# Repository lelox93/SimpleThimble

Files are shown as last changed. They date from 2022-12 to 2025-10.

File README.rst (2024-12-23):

Example: Basic Sphinx project for Read the Docs
===============================================



.. This README.rst should work on Github and is also included in the Sphinx documentation project in docs/ - therefore, README.rst uses absolute links for most things so it renders properly on GitHub

This example shows a basic Sphinx project with Read the Docs. You're encouraged to view it to get inspiration and copy & paste from the files in the source code. If you are using Read the Docs for the first time, have a look at the official `Read the Docs Tutorial <https://docs.readthedocs.io/en/stable/tutorial/index.html>`__.

📚 `docs/ <https://github.com/readthedocs-examples/example-sphinx-basic/blob/main/docs/>`_
    A basic Sphinx project lives in ``docs/``. All the ``*.rst`` make up sections in the documentation.
⚙️ `.readthedocs.yaml <https://github.com/readthedocs-examples/example-sphinx-basic/blob/main/.readthedocs.yaml>`_
    Read the Docs Build configuration is stored in ``.readthedocs.yaml``.
⚙️ `docs/conf.py <https://github.com/readthedocs-examples/example-sphinx-basic/blob/main/docs/conf.py>`_
    Both the configuration and the folder layout follow Sphinx default conventions. You can change the `Sphinx configuration values <https://www.sphinx-doc.org/en/master/usage/configuration.html>`_ in this file
📍 `docs/requirements.txt <https://github.com/readthedocs-examples/example-sphinx-basic/blob/main/docs/requirements.txt>`_ and `docs/requirements.in <https://github.com/readthedocs-examples/example-sphinx-basic/blob/main/docs/requirements.in>`_
    Python dependencies are `pinned <https://docs.readthedocs.io/en/latest/guides/reproducible-builds.html>`_ (uses `pip-tools <https://pip-tools.readthedocs.io/en/latest/>`_). Make sure to add your Python dependencies to ``requirements.txt`` or if you choose `pip-tools <https://pip-tools.readthedocs.io/en/latest/>`_, edit ``docs/requirements.in`` and remember to run ``pip-compile docs/requirements.in``.
💡 `docs/api.rst <https://github.com/readthedocs-examples/example-sphinx-basic/blob/main/docs/api.rst>`_
    By adding our example Python module ``lumache`` in the reStructuredText directive ``:autosummary:``, Sphinx will automatically scan this module and generate API docs.
💡 `docs/usage.rst <https://github.com/readthedocs-examples/example-sphinx-basic/blob/main/docs/usage.rst>`_
    Sphinx can automatically extract API documentation directly from Python modules, using for instance the ``:autofunction:`` directive.
💡 `lumache.py <https://github.com/readthedocs-examples/example-sphinx-basic/blob/main/lumache.py>`_
    API docs are generated for this example Python module - they use *docstrings* directly in the documentation, notice how this shows up in the rendered documentation.
🔢 Git tags versioning
    We use a basic versioning mechanism by adding a git tag for every release of the example project. All releases and their version numbers are visible on `example-sphinx-basic.readthedocs.io <https://example-sphinx-basic.readthedocs.io/en/latest/>`__.
📜 `README.rst <https://github.com/readthedocs-examples/example-sphinx-basic/blob/main/README.rst>`_
    Contents of this ``README.rst`` are visible on Github and included on `the documentation index page <https://example-sphinx-basic.readthedocs.io/en/latest/>`_ (Don't Repeat Yourself).
⁉️ Questions / comments
    If you have questions related to this example, feel free to can ask them as a Github issue `here <https://github.com/readthedocs-examples/example-sphinx-basic/issues>`_.

Example Project usage
---------------------

This project has a standard Sphinx layout which is built by Read the Docs almost the same way that you would build it locally (on your own laptop!).

You can build and view this documentation project locally - we recommend that you activate `a local Python virtual environment first <https://packaging.python.org/en/latest/guides/installing-using-pip-and-virtual-environments/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>`_:

.. code-block:: console

    # Install required Python dependencies (Sphinx etc.)
    pip install -r docs/requirements.txt

    # Enter the Sphinx project
    cd docs/
    
    # Run the raw sphinx-build command
    sphinx-build -M html . _build/

You can also build the documentation locally with ``make``:

.. code-block:: console

    # Enter the Sphinx project
    cd docs/
    
    # Build with make
    make html
    
    # Open with your preferred browser, pointing it to the documentation index page
    firefox _build/html/index.html

Using the example in your own project
-------------------------------------

If you are new to Read the Docs, you may want to refer to the `Read the Docs User documentation <https://docs.readthedocs.io/>`_.

If you are copying this code in order to get started with your documentation, you need to:

#. place your ``docs/`` folder alongside your Python project. If you are starting a new project, you can adapt the `pyproject.toml` example configuration.
#. use your existing project repository or create a new repository on Github, GitLab, Bitbucket or another host supported by Read the Docs
#. copy ``.readthedocs.yaml`` and the ``docs/`` folder into your project.
#. customize all the files, replacing example contents.
#. add your own Python project, replacing the ``pyproject.toml`` configuration and ``lumache.py`` module.
#. rebuild the documenation locally to see that it works.
#. *finally*, register your project on Read the Docs, see `Importing Your Documentation <https://docs.readthedocs.io/en/stable/intro/import-guide.html>`_.

Read the Docs tutorial
----------------------

To get started with Read the Docs, you may also refer to the `Read the Docs tutorial <https://docs.readthedocs.io/en/stable/tutorial/>`__.
It provides a full walk-through of building an example project similar to the one in this repository.

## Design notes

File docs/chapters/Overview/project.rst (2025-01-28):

AugmentedWearEdu Project
+++++++++++++++++++++++++++++++++++++++++

The main objective of project is to introduce a novel framework for e-Learning consisting of including haptic experiences to enable digital access to laboratories in higher education. This will be achieved by combining both virtual reality (VR) and augmented reality (AR) tools with a novel generation of wearable haptic devices. This combination of low-cost commercial off-the-shelf (COTS) technology (using open-source software and simple physical devices) will make learning in a laboratory and hapto-audiovisual environment possible.

pref
|

One of the biggest drawbacks of the majority of E-learning existing solutions, is that limited support is provided to hands-on laboratory work and practical experiences. Hands-on experiences are essential to significantly advance learning, especially in science, technology, engineering, and mathematics (STEM) departments. The project AugmentedWearEdu will make it possible to engage students in a fully-immersive 3D virtual/augmented educational environment, contributing to performing lab work in a fully-immersive, open, and, most importantly, distance laboratory learning. 

Within this project, the SimpleThimble device will be used to provide haptic feedback to the user, allowing them to feel the virtual environment in a realistic way. The device will be used in combination with VR tools to create a fully immersive learning experience.

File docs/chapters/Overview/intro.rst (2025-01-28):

Welcome to Simple Thimble!
+++++++++++++++++++++++++++++++++++++++++

**Simple Thimble** is an *open-source* and *low-cost* project to build your own VR-enabled force feedback device. It is designed to be easy to 
assemble and use, and can be used with ``Unity`` virtual environment development platform. Moreover the :ref:`3D models<3dPrintingIntro>` for this device can be downloaded from this guide and 3D printed at home!

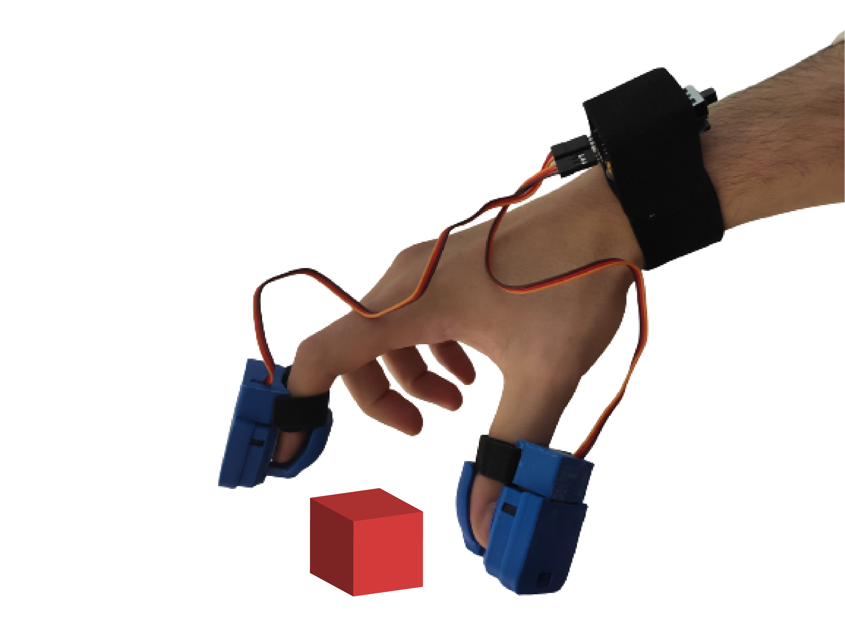
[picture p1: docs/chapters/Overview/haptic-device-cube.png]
Haptic Device

|

Features
-------------------------------------------------------

* **Open-source**: All the hardware and software components are open-source, so you can customize the device to your needs. 
* **Low-cost**: Simple Thimble is designed to be affordable, so anyone can build 
  their own force feedback device. 
* **Easy to assemble**: The device is designed to be easy to assemble, so you 
  don't need any special tools or skills. 
* **VR Compatible**: Simple Thimble is compatible with Unity virtual 
  environment development platform, so you can use it while developing virtual world applications.
* **Force feedback**: Simple Thimble provides realistic force feedback, so you can feel the environment in virtual reality.

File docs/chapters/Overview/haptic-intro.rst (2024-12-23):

Haptic Devices: an overview
+++++++++++++++++++++++++++++++

Haptic devices are tactile feedback devices that allow users to interact with virtual environments. They provide a sense of touch and force feedback to the user, allowing them to feel the effects of their actions in a virtual environment. Haptic devices are used in a variety of applications, including gaming, medical training, and virtual reality.

What is an haptic thimble?
===========================

A haptic thimble is a device used to provide tactile feedback to a user. It is typically worn on the finger and provides a physical sensation when 
interacting with a virtual environment. The thimble can be used to simulate the feeling of touching objects in a virtual world, allowing users to experience a more realistic and immersive experience. 

Grasping Cubes

We can find two simple implementations of an haptic thimble, by providing the fingertip with a vibration of by squeezing it.

Haptic thimble anatomy
----------------------

The haptic thimble is composed of several components, including a motor, sensors, and some mechanical components. The motor is used to generate vibrations, which are then transmitted to the user by using sensors' data. The sensors detect the user's movements and provide feedback to the motor, allowing it to adjust the intensity of the force accordingly.

Applications for an haptic thimble
----------------------------------

The haptic thimble is used in a variety of applications, including virtual reality, gaming, and medical training. It can be used to simulate the feeling of touching objects in a virtual environment, allowing users to experience a more realistic and immersive experience. 

Hand Grasping Cube

Additionally, it can be used to provide tactile feedback during medical procedures, allowing doctors to practice their skills without putting patients at risk.

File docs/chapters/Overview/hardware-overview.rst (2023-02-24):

Hardware Overview of Simple Thimble
++++++++++++++++++++++++++++++++++++

Simple Thimble is a DIY haptic thimble that provides tactile feedback to the user. It is designed to be easy to assemble and use, and can be used for a variety of applications.

Components
===========

Simple Thimble consists of the following components:

-   an ESP32 microcontroller
-   an ESP8266 microcontroller (WeMoS D1 mini)
-   a battery shield for the D1 mini board
-   a Li-Po 3.7V battery
-   a switch
-   a standard SG90 servomotor
-   3D printed thimble parts
-   velcro strips
-   neoprene tape

Parts role inside the thimble
===============================

In the following we will analyze the role that each of the hardware components will have in our thimble.

The ESP32 microcontroller
---------------------------
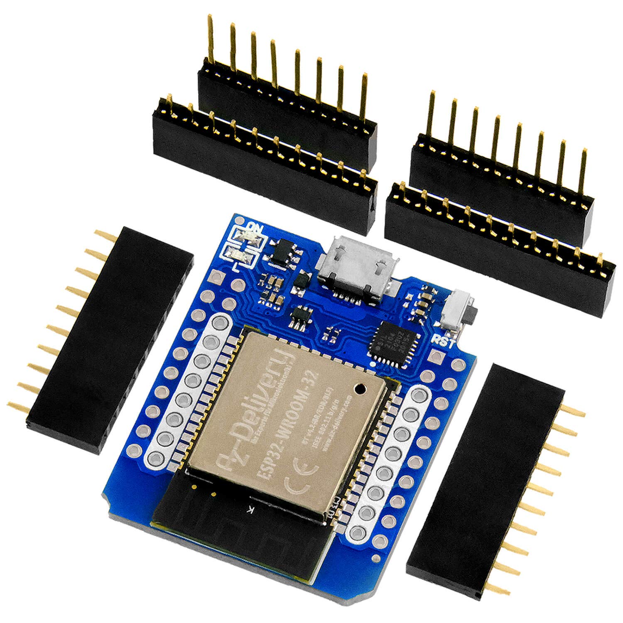
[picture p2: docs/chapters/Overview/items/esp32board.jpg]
esp32board

The ESP32 microcontroller function as a dongle in our application. It will be connected via USB to the 
computer to bridge wirelessly received data into the computer using serial communication. The use of the 
popular ESP32 microcontroller will allow us to use the ESP-NOW protocol to have a reliable connection 
success between modules. Moreover, we don't have to deal with bluetooth protocol version, which may not 
be present or vary from one pc to the other.

The ESP8266 microcontroller
---------------------------
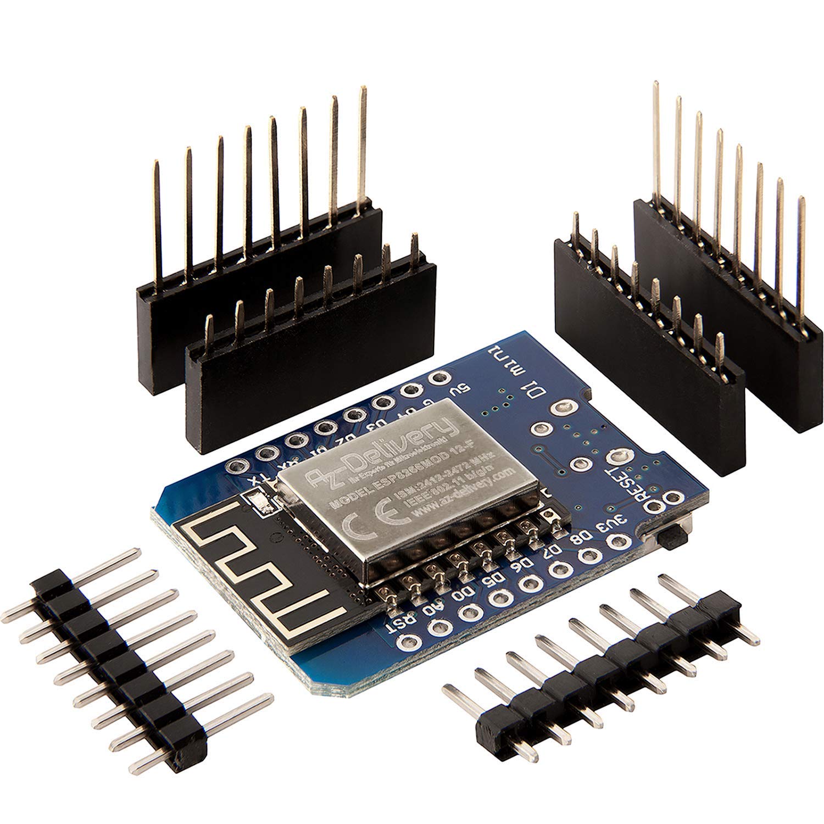
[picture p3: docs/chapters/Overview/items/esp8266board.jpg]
esp8266board

The ESP8266 microcontroller is the wearable ESP microcontroller which will recieve data wirelessly from 
the dongle connected to the computer. This microcontroller will control also the two servomotors which 
are inside each thimble.

Other electronic components (battery shield, proto shield, Li-Po battery, switch)
---------------------------------------------------------------------------------------
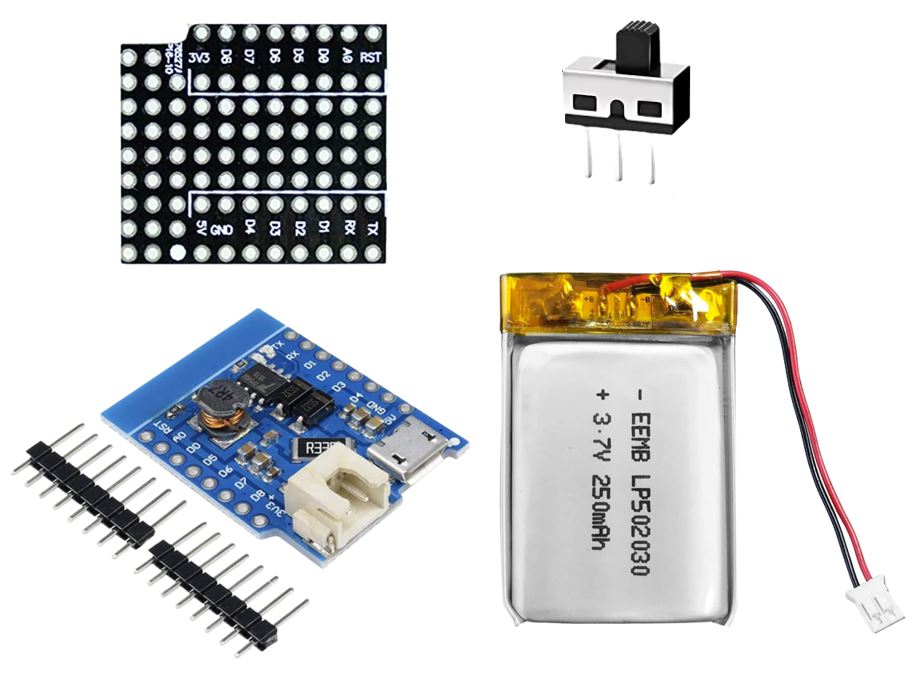
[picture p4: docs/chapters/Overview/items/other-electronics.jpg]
other-electronics

Those parts are useful to make the connection of all components faster. The battery shield 
is used to add the circuit necessary to charge a Li-Po battery. The proto shield is used to easily make 
connections between the microcontroller, servomotors, battery management circuit and switch.

Other mechanical and mechatronic components (servomotors, velcro strips and neoprene tape)
---------------------------------------------------------------------------------------
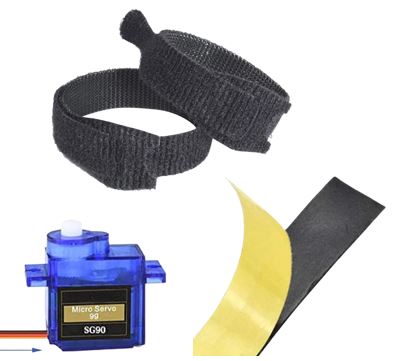
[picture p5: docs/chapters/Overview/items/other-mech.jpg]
other-mech

Those parts are necessary to assemble the thimble. The servomotor is needed to convert the electrical 
control signals to the mechanical motion necessary to apply the pressure to the fingertip pulp. Velcro 
strips are necessary to secure the thimble to the finger and the neoprene tape is applied to make the 
thimble more comfortable.

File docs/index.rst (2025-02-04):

.. Read the docs - example documentation master file, created by
   sphinx-quickstart on Tue Dec 13 11:49:45 2022.
   You can adapt this file completely to your liking, but it should at least
   contain the root `toctree` directive.

Welcome to Simple Thimble documentation!
===================================================

.. ENG ITA

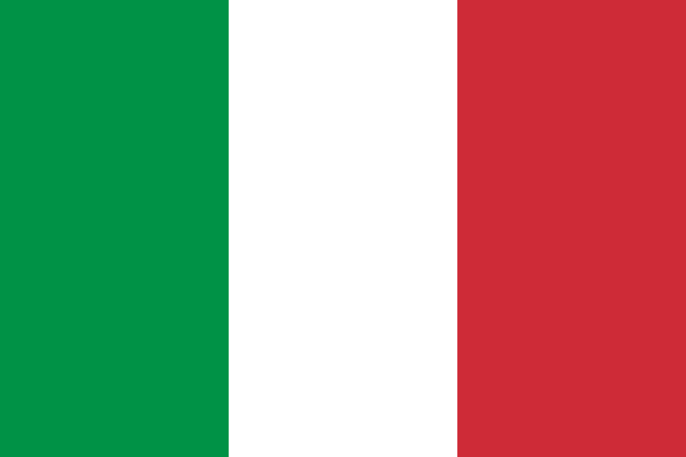
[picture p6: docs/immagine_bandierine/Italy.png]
ita flag
.. 

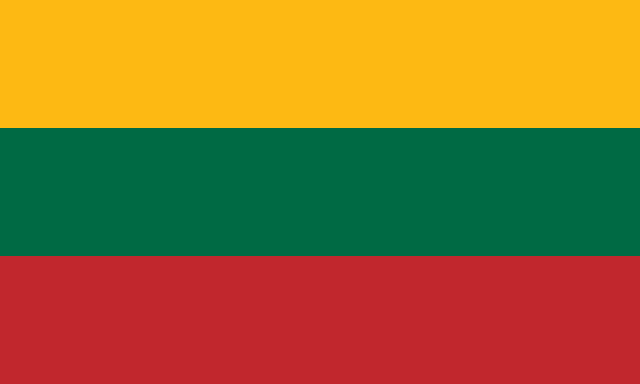
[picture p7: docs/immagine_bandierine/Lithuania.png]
Lithuania flag
   

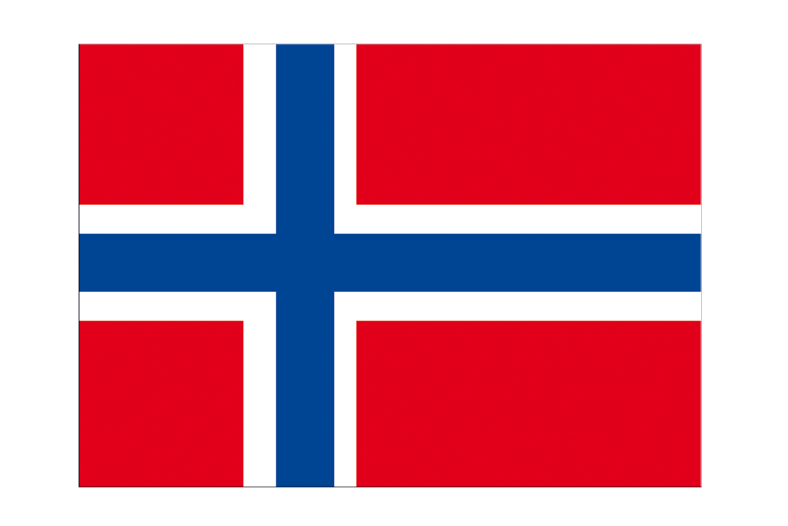
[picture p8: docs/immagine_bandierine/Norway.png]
   

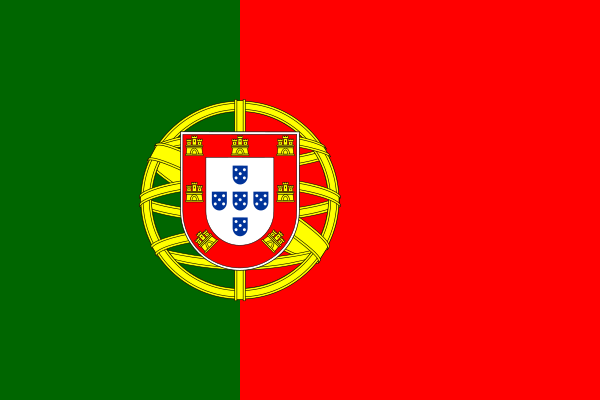
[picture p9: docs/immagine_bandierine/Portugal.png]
   

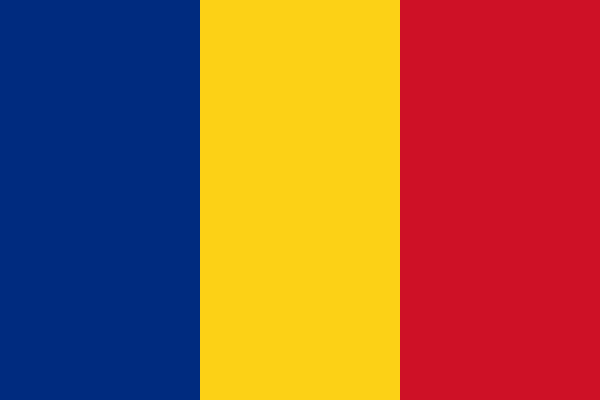
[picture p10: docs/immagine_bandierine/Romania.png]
   

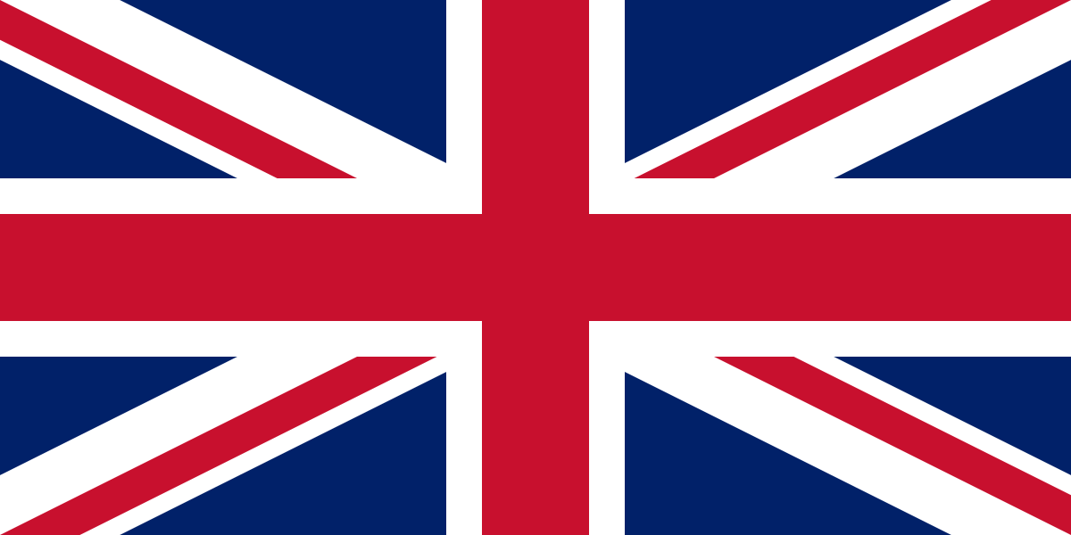
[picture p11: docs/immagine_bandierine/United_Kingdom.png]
.. 
..       :alt: Lithuania flag
..       :width: 30 px
..       :align: left
..       :target: https://simplethimble.readthedocs.io/en/latest/

SimpleThimble is the first *open-source* and *low-cost* project to build your **own** VR-enabled **force feedback device**.

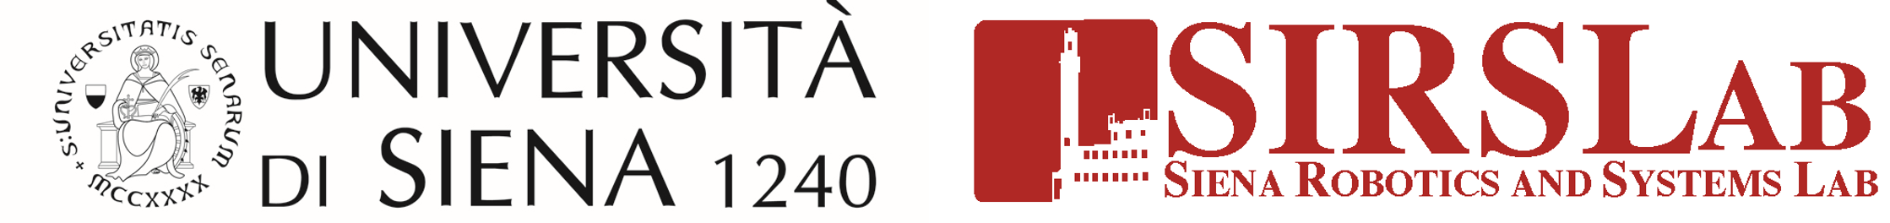
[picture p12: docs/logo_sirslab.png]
.. 
..    :alt: pref
..    :align: center
.. |

.. toctree::
   :maxdepth: 2
   :caption: Overview:

   Welcome to Simple Thimble! <chapters/Overview/intro>
   chapters/Overview/haptic-intro
   chapters/Overview/hardware-overview

.. toctree::
   :maxdepth: 2
   :caption: 3D Printing:

   chapters/3D-Printing/3D-printing-intro
   chapters/3D-Printing/main-box/main-box
   chapters/3D-Printing/rack-pinion/rack-pinion
   chapters/3D-Printing/covers/covers
   
.. toctree::
   :maxdepth: 2
   :caption: Hardware:

   chapters/Hardware/bom
   chapters/Hardware/hardware-assembly

.. toctree::
   :maxdepth: 2
   :caption: Firmware:

   chapters/Firmware/firmware-intro
   chapters/Firmware/firmware-test
   chapters/Firmware/firmware-get-mac
   chapters/Firmware/firmware-dongle
   chapters/Firmware/firmware-onboard
   chapters/Firmware/firmware-final-test

.. toctree::
   :maxdepth: 2
   :caption: VR application:

   chapters/VR application/vr-intro
   chapters/VR application/vr-desktop
   chapters/VR application/vr-leap
   chapters/VR application/vr-oculus

.. toctree::
   :maxdepth: 2
   :caption: Course:

   chapters/Course/software-intro
   chapters/Course/software-install

.. Indices and tables
   ==================

   * :ref:`genindex`
   * :ref:`modindex`
   * :ref:`search`

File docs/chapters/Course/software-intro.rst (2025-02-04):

SimpleThimble Course: Overview and Objectives
=============================================

Welcome to the SimpleThimble Course! This course is designed to help you understand the principles of haptic feedback and how to implement them using the SimpleThimble device. By the end of this course, you will have a solid understanding of haptic feedback, the hardware components of the SimpleThimble, and how to develop applications for the device.

You will learn how to:

- Assemble the SimpleThimble device
- Program the firmware for the device
- Develop VR applications using the SimpleThimble

Participants are asked to be divided into groups of 3-4 people. Each group receive the necessary components to assemble the device as shown in the following figure:

pref

|

The final devices will be used to develop a virtual reality application that demonstrates the capabilities of the SimpleThimble device. The application will allow users to interact with virtual objects and feel the haptic feedback generated by the device.
The version of the device includes a thimble to be worn on the index finger, which is used to interact with the virtual environment:

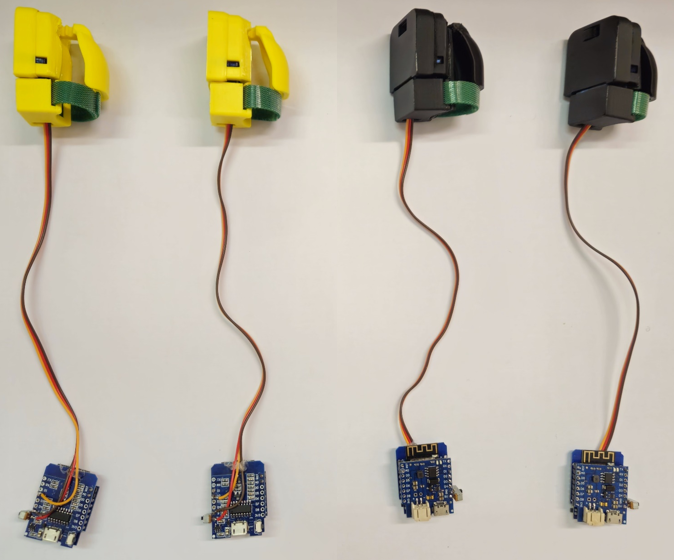
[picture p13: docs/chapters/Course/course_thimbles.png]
pref


|

The material provided includes:

- Firmware for microcontrollers: :download:`here <simpleThimble_firmware.rar>`.
- Unity package for virtual reality applications: :download:`here <simpleThimble_course.unitypackage>`.

The next page will guide you in setting up the necessary software to start developing applications for the SimpleThimble.

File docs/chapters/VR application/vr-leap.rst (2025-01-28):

VR Application: Leap Motion
=======================================================

The Leap Motion controller is a hand-tracking device that uses a combination of cameras and infrared sensors to track the movement of hands and fingers with high accuracy and low latency.

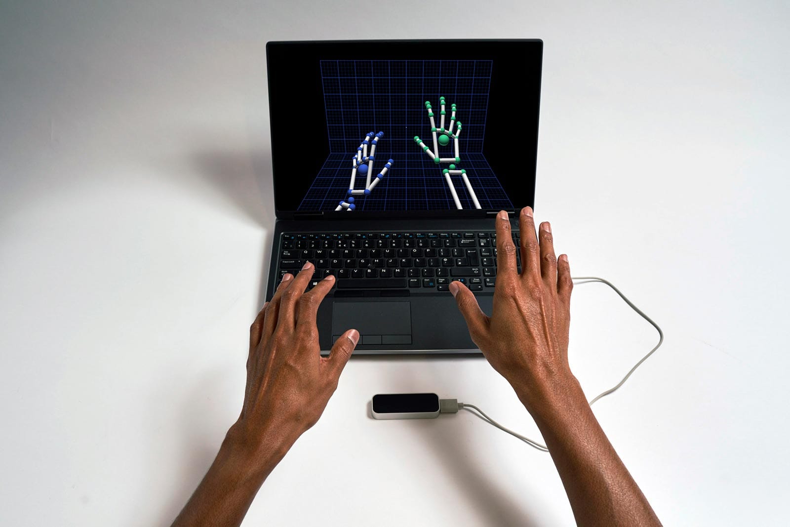
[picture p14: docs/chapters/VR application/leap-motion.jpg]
Leap Motion Controller

|

This guide explains how to set up Leap Motion hand tracking with Unity using the Leap Motion Unity Modules, Core Assets, and Interaction Engine.

Prerequisites
-------------

Ensure you have the following:

- **PC Requirements**: Windows 10 or later, or macOS.
- **Hardware**: Leap Motion Controller or Ultraleap device, ESP32-based dongle, and SimpleThimble thimbles.
- **Unity Installation**: Unity 2020.3.28f1 or later (LTS versions recommended).
- **Software Tools**: Unity Hub, Visual Studio (for script editing).

Downloading Leap Motion Gemini
-----------------------------

We will need a specific version of Leap Motion called Gemini, as this developer kit integrates well with Unity packages.

To download **Leap Motion Gemini 5.20.0**, click `here <https://leap2.ultraleap.com/downloads/leap-motion-controller/>`_.

After installation, attach your Leap Motion to the PC and launch the Leap Motion visualizer to ensure it is working correctly. You should see an interface similar to this:

Leap Motion Visualizer

|

The following steps will guide you through setting up the SimpleThimble Unity project with Leap Motion hand tracking.

**Step 1**: Download and Open the SimpleThimble Unity Project
---------------------------------------------------------

1. **Download the SimpleThimble Project**:  
   :download:`here <SimpleThimble_leapProject.rar>`.
2. **Extract the Folder**:  
   Extract the ``Simplethimble_leapProject`` folder from the compressed file.
3. **Open the Project in Unity**:  
   - Open **Unity Hub**.
   - Add the extracted project folder as project from disk.
   - Select **Unity 2020.3.28f1** as the version for the project.

After opening the project, you should see a Unity IDE environment similar to this:

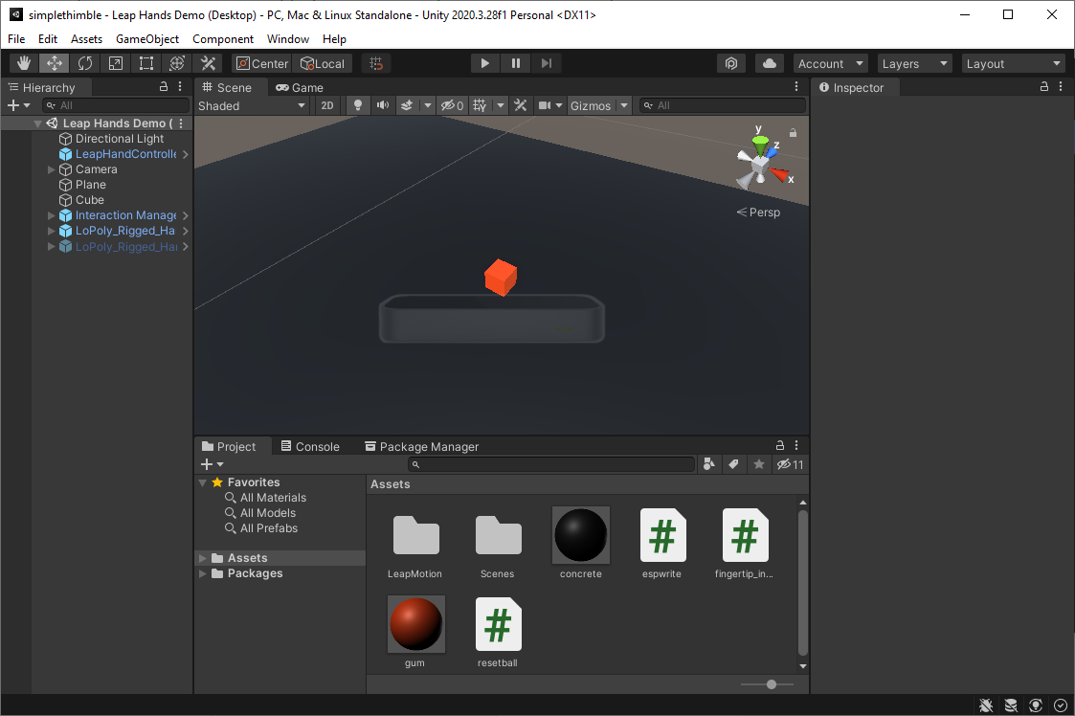
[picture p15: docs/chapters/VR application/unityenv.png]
Unity IDE

|   

**Step 2**: Configure the ESP32 Dongle for SimpleThimble
----------------------------------------------------

1. Locate the C# script ``espwrite.cs`` in the Unity Project:
   - Path: ``Assets/espwrite.cs``.
2. Open the script in Visual Studio by double-clicking its icon.
3. Modify the COM port number at **line 14** to match the port assigned to your ESP32 dongle.  
   Example: Change ``COM21`` to the correct COM port for your computer.

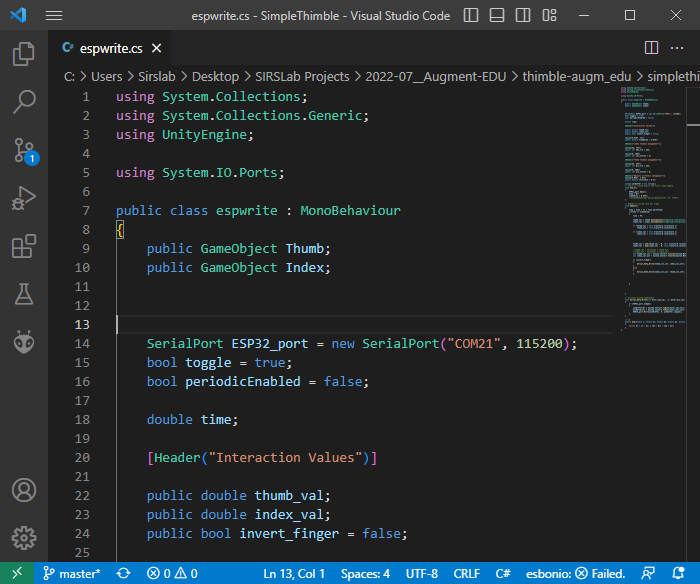
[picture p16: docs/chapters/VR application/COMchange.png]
Change COM Port


4. Save the changes and return to Unity.

..    In case same drivers are missing, we suggest following the optional step below. Otherwise, you can directly go to **Step 3**. 
.. |

.. **[Optional]**: Install Leap Motion Unity Modules
.. -----------------------------------------

.. 1. **Download and Import Leap Motion Unity Modules**:
..    - **Version 4.8.0**: `Download here <https://www2.leapmotion.com/downloads/unity-modules/v4.8.0>`_.
..    - Import into Unity:
..      - Go to **Assets > Import Package > Custom Package**.
..      - Select the ``.unitypackage`` file and follow the prompts.

.. 2. **Install Leap Motion Core Assets**:
..    - **Version 4.3.4**: `Download here <https://github.com/ultraleap/UnityPlugin/releases/download/Release-CoreAsset-4.3.4/Leap_Motion_Core_Assets_4.3.4.unitypackage>`_.
..    - Import into Unity using the same process as above.

.. 3. **Install Leap Motion Interaction Engine**:
..    - **Version 1.1.1**: `Download here <https://github.com/ultraleap/UnityPlugin/releases/download/Release-InteractionEngine-1.1.1/Leap_Motion_Interaction_Engine_1.1.1.unitypackage>`_.
..    - Import into Unity.

.. 4. **Add Leap Motion Components to Your Scene**:
..    - Add the **LeapXRServiceProvider** prefab to your scene.
..    - Configure Unity's XR settings:
..      - Go to **Edit > Project Settings > XR Plug-in Management**.
..      - Ensure the project is compatible with your VR platform.

**Step 3**: Test SimpleThimble with Leap Motion
-------------------------------------------

1. **Connect Devices**:
   - Connect the Leap Motion Controller and ESP32 dongle to your PC.
   - Ensure the SimpleThimble thimbles are battery-powered.

2. **Start the Project**:
   - Open the project in Unity.
   - Click on **Game** view and select **Maximize on Play**.
   - Press the Play button in Unity.

Unity First Play

3. **Interact with the Scene**:
   - Move your hand over the Leap Motion Controller to see it in the Unity scene.
   - Touch the cube with the SimpleThimble thimbles to experience haptic feedback.

Thimble Interaction

4. **Reset the Cube**:
   - If the cube falls out of the Leap Motion workspace, press **"R"** on your keyboard to reset it to its initial position.

Final Step: Grasp and Feel the Virtual Cube
-------------------------------------------

Wear the SimpleThimble devices, grasp the red cube in the scene, and feel the cutaneous haptic feedback.

Grasping the Cube
|

Troubleshooting
---------------

1. Verify the Leap Motion Controller and ESP32 dongle are properly connected.
2. Ensure you are using the correct Unity version and modules.
3. For Leap Motion issues, visit the `Leap Motion Support Center <https://support.leapmotion.com/>`_.

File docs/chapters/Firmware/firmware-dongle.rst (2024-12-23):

The dongle firmware code 
++++++++++++++++++++++++++++

This firmware enables an ESP32 device to function as a dongle that can read serial data from a connected device 
and transmit it wirelessly to an ESP8266 device using the ESP-NOW protocol.

The ESP32 dongle reads serial data from a connected device and transmits it wirelessly to the ESP8266 device 
using the low-power ESP-NOW protocol, which is specifically designed for IoT devices.

The code to upload tot he ESP32 dongle is the following:

.. code-block:: arduino

    #include <Arduino.h>
    #include <esp_now.h>
    #include <WiFi.h>

    // Define ESP8266 Mac address (first peer)
    uint8_t mac_peer1[] = { 0x48, 0x55, 0x19, 0xC6, 0x6E, 0x30 };

    // Define peer info struct for first device
    esp_now_peer_info_t peer1;

    // Define struct containing force sensed data
    typedef struct force_data {
        uint16_t force_sensed_index = 0;
        uint16_t force_sensed_thumb = 0;
    };

    // Initialize force_data struct
    struct force_data forceData;

    // Define variables for raw and received force sensed data
    byte raw_value_index = 0, raw_value_thumb = 0;
    uint8_t received_value_index = 0, received_value_thumb = 0;

    void setup() {
        // Start serial communication
        Serial.begin(115200);

        // Set device as a Wi-Fi Station
        WiFi.mode(WIFI_STA);

        // Init ESP-NOW
        if (esp_now_init() != ESP_OK) {
            Serial.println("Error initializing ESP-NOW");
            return;
        }

        // Set peer1's address and channel, and disable encryption
        memcpy(peer1.peer_addr, mac_peer1, 6);
        peer1.channel = 1;
        peer1.encrypt = 0;

        // Register peer1
        Serial.println("Registering a peer 1");
        if (esp_now_add_peer(&peer1) == ESP_OK) {
            Serial.println("Peer 1 added");
        }
    }

    void loop() {
        // Check for available serial data
        if (Serial.available() > 1) {

            // Read raw force sensed data from serial input
            raw_value_index = (byte)(Serial.read());
            raw_value_thumb = (byte)(Serial.read());

            // Map raw force sensed values to a range of 0-255
            received_value_index = map((int)(raw_value_index), 36, 255, 0, 255);
            received_value_thumb = map((int)(raw_value_thumb), 36, 255, 0, 255);

            // Store mapped force sensed values in forceData struct
            forceData.force_sensed_index = received_value_index;
            forceData.force_sensed_thumb = received_value_thumb;

            // Send forceData to peer1 using ESP-NOW
            esp_now_send(peer1.peer_addr, (uint8_t *)&forceData, sizeof(forceData));

            // Print force sensed data to serial monitor
            Serial.println("-----------------");
            Serial.print("index finger: ");
            Serial.print(forceData.force_sensed_index);
            Serial.print("\tthumb: ");
            Serial.println(forceData.force_sensed_thumb);
        }
    }

|

Commands
========

The following is a breakdown of the code with comments explaining each command:

Libraries and Struct Definition
-------------------------------
The following code defines a struct named force_data which contains two variables representing the force sensed on the index and thumb fingers.

.. code-block:: arduino
    
    #include <Arduino.h>
    #include <esp_now.h>
    #include <WiFi.h>

    // Define struct containing force sensed data
    typedef struct force_data {
        uint16_t force_sensed_index = 0;
        uint16_t force_sensed_thumb = 0;
    };

    // Initialize force_data struct
    struct force_data forceData;

    // Define variables for raw and received force sensed data
    byte raw_value_index = 0, raw_value_thumb = 0;
    uint8_t received_value_index = 0, received_value_thumb = 0;

Setup Function
--------------
The following code is the setup function which runs once at the beginning of the code:
Starts serial communication
Sets device as a Wi-Fi Station
Initializes ESP-NOW
Sets peer1's address and channel, and disables encryption
Registers peer1.

.. code-block:: arduino
    
    void setup() {
        // Start serial communication
        Serial.begin(115200);

        // Set device as a Wi-Fi Station
        WiFi.mode(WIFI_STA);

        // Init ESP-NOW
        if (esp_now_init() != ESP_OK) {
            Serial.println("Error initializing ESP-NOW");
            return;
        }

        // Set peer1's address and channel, and disable encryption
        memcpy(peer1.peer_addr, mac_peer1, 6);
        peer1.channel = 1;
        peer1.encrypt = 0;

        // Register peer1
        Serial.println("Registering a peer 1");
        if (esp_now_add_peer(&peer1) == ESP_OK) {
            Serial.println("Peer 1 added");
        }
    }

Loop Function
-------------
The following code is the loop function, which runs continuously while the device is powered. It checks for available serial data, reads the raw force sensed data from serial input, maps the raw force sensed values to a range of 0-255, stores the mapped force sensed values in forceData struct, and sends forceData to peer1 using ESP-NOW.

.. code-block:: arduino

    void loop() {
        // Check for available serial data
        if (Serial.available() > 1) {

            // Read raw force sensed data from serial input
            raw_value_index = (byte)(Serial.read());
            raw_value_thumb = (byte)(Serial.read());

            // Map raw force sensed values to a range of 0-255
            received_value_index = map((int)(raw_value_index), 36, 255, 0, 255);
            received_value_thumb = map((int)(raw_value_thumb), 36, 255, 0, 255);

            // Store mapped force sensed values in forceData struct
            forceData.force_sensed_index = received_value_index;
            forceData.force_sensed_thumb = received_value_thumb;

            // Send forceData to peer1 using ESP-NOW
            esp_now_send(peer1.peer_addr, (uint8_t *)&forceData, sizeof(forceData));

            // Print force sensed data to serial monitor
            Serial.println("-----------------");
            Serial.print("index finger: ");
            Serial.print(forceData.force_sensed_index);
            Serial.print("\tthumb: ");
            Serial.println(forceData.force_sensed_thumb);
        }
    }

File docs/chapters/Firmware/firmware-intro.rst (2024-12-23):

Firmware: an introduction
+++++++++++++++++++++++++

What is a firmware?
====================

Firmware is a type of software that is embedded into a hardware device. It provides the necessary instructions for how the device communicates with the other computer hardware. Firmware is typically stored in the read-only memory of a device and is often the first software to run when powered on. It is responsible for basic operations such as booting up the device, managing system resources and providing an interface for applications to interact with the hardware.

Integrated Development Environment
==================================

An IDE (Integrated Development Environment) is a software application that provides comprehensive facilities to computer programmers for software development. It typically consists of a source code editor, build automation tools, and a debugger. An IDE can make it easier to write and debug code by providing features such as auto-completion, syntax highlighting, and debugging tools.

Arduino IDE 2.0
===============

We will use one of the most simple IDEs that we can find online, and it is the `Arduino IDE 2.0 <https://docs.arduino.cc/software/ide-v2>`_.

Setup the IDE for the ESP based boards
----------------------------------------

 To be able to upload codes to the ESP based boards you need to insert the link of their hardware list.
 Go to File -> Preferences and a window will pop-up. Scroll down and find the box "Additional boards manager URLs".
 Click on the blue icon on the rigth and add the links:
 
 * ``https://dl.espressif.com/dl/package_esp32_index.json``
 * ``https://raw.githubusercontent.com/espressif/arduino-esp32/gh-pages/package_esp32_index.json``

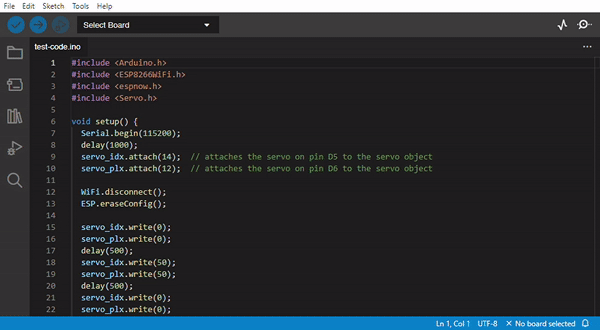
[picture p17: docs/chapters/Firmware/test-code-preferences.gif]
pref


|

Now, clicking on the *Boards Manager* button on the left column you can search for all ESP based boards.
By writing "esp" in the search bar, you will filter boards and by scrolling down you will find both the 
option to install ESP32 boards and ESP8266 boards, it is necessary to click install.

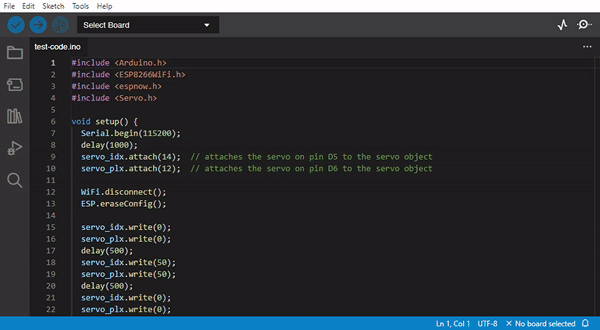
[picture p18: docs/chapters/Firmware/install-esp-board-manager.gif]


|

Now you are ready to upload your firmware codes to all possible ESP boards!

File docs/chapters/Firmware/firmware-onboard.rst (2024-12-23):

The final Simple Thimble onboard firmware
+++++++++++++++++++++++++++++++++++++++++++++
.. _onboardFirmware:

This firmware enables an ESP8266 device to receive data using the ESP-NOW protocol.

The code to upload to the ESP8266 device is the following:

.. code-block:: arduino
    
    #include <Arduino.h>
    #include <ESP8266WiFi.h>
    #include <espnow.h>
    #include <Servo.h>

    // Define struct containing force sensed data
    typedef struct force_data {
    uint16_t force_sensed_index = 0;
    uint16_t force_sensed_thumb = 0;
    } force_data;

    // Initialize force_data struct
    struct force_data forceData;

    // Create servo objects
    Servo servo_index;
    Servo servo_thumb;

    // Define Master Mac address
    uint8_t macMaster[] = {0x40, 0x22, 0xD8, 0x3C, 0x1C, 0xCC};

    // Initialize other auxiliary variables
    int limit = 180;
    int offset_index = 0;
    int offset_thumb = 0;

    // Define the callback function connected to the event of receiving ESP-NOW data
    void onDataReceiver(uint8_t * mac, uint8_t *incomingData, uint8_t len) {
    memcpy(&forceData, incomingData, sizeof(forceData));
    servo_index.write(map(forceData.force_sensed_index, 0, 255, offset_index, limit));
    servo_thumb.write(map(forceData.force_sensed_thumb, 0, 255, offset_thumb, limit));
    ESP.wdtFeed();
    }

    void setup() {
    // Start serial communication
    Serial.begin(115200);

    // Attach the servos to their respective pins
    servo_index.attach(14);   // pin D5
    servo_thumb.attach(12);   // pin D6

    // Disconnect from WiFi and erase the stored config
    WiFi.disconnect();
    ESP.eraseConfig();

    // Start up sequence
    servo_index.write(0);
    servo_thumb.write(0);
    delay(500);
    servo_index.write(50);
    servo_thumb.write(50);
    delay(500);
    servo_index.write(0);
    servo_thumb.write(0);

    // Set device as a Wi-Fi Station
    WiFi.mode(WIFI_STA);

    // Init ESP-NOW
    if (esp_now_init() != 0) {
        Serial.println("Error initializing ESP-NOW");
        return;
    }

    // Set the device to act as both a sender and receiver using ESP-NOW
    esp_now_set_self_role(ESP_NOW_ROLE_COMBO);
    
    // Add the MAC address of the master device as a peer for ESP-NOW communication
    esp_now_add_peer(macMaster, ESP_NOW_ROLE_COMBO, 1, NULL, 0);

    // We can register the receiver callback function
    esp_now_register_recv_cb(onDataReceiver);
    }

    void loop() {
    // loop does nothing
    }

|

Commands
========

The following is a breakdown of the code with comments explaining each command:

Libraries and Struct Definition
--------------------------------
The following code defines a struct named force_data which contains two variables representing the force sensed on the index and thumb fingers.

.. code-block:: arduino

    #include <Arduino.h>
    #include <ESP8266WiFi.h>
    #include <espnow.h>
    #include <Servo.h>
    
    typedef struct force_data {
        uint16_t force_sensed_index = 0;
        uint16_t force_sensed_thumb = 0;
    } force_data;

    struct force_data forceData;

Create Servo Objects and Define Auxiliary Variables
---------------------------------------------------
The following code creates objects for two servos named servo_index and servo_thumb and defines some auxiliary variables for the code.

.. code-block:: arduino

    Servo servo_index;
    Servo servo_thumb;

    int limit = 180;
    int offset_index = 0;
    int offset_thumb = 0;

Callback Function for ESP-NOW Data Reception
---------------------------------------------
The following code defines a callback function that will be called whenever the device receives data using ESP-NOW. It copies the incoming 
data into the forceData struct, maps the force values to the servo positions, and feeds the ESP watchdog timer.

.. code-block:: arduino

    void onDataReceiver(uint8_t * mac, uint8_t *incomingData, uint8_t len) {
        memcpy(&forceData, incomingData, sizeof(forceData));
        servo_index.write(map(forceData.force_sensed_index, 0, 255, offset_index, limit));
        servo_thumb.write(map(forceData.force_sensed_thumb, 0, 255, offset_thumb, limit));
        ESP.wdtFeed();
    }

Setup Function
--------------

The following code is the setup function which runs once at the beginning of the code. It initializes the serial communication, attaches the servos to their pins, disconnects from any previous WiFi connections, performs a servo startup sequence, sets the device as a Wi-Fi station, initializes ESP-NOW and sets the device as both a sender and receiver, adds the master device as a peer for ESP-NOW communication, and registers the callback function for receiving data.

.. code-block:: arduino

    void setup() {
        Serial.begin(115200);

        servo_index.attach(14);
        servo_thumb.attach(12);

        WiFi.disconnect();
        ESP.eraseConfig();

        servo_index.write(0);
        servo_thumb.write(0);
        delay(500);
        servo_index.write(50);
        servo_thumb.write(50);
        delay(500);
        servo_index.write(0);
        servo_thumb.write(0);

        WiFi.mode(WIFI_STA);

        if (esp_now_init() != 0) {
          Serial.println("Error initializing ESP-NOW");
          return;
        }

        esp_now_set_self_role(ESP_NOW_ROLE_COMBO);
        esp_now_add_peer(macMaster, ESP_NOW_ROLE_COMBO, 1, NULL, 0);

        esp_now_register_recv_cb(onDataReceiver);
   }

Loop Function
--------------

The following code is the loop function, which runs continuously while the device is powered. It currently does nothing.

.. code-block:: arduino
    
    void loop() {
        // loop does nothing
    }

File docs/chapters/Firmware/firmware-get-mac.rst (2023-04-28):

How to get MAC adderesses of the boards 
++++++++++++++++++++++++++++++++++++++++++++

An important step to set up our device is to get the `MAC address <https://en.wikipedia.org/wiki/MAC_address>`_ of our microcontrollers. 
This is necessary to connect the boards using their wireless communication standard: `esp-now <https://docs.espressif.com/projects/esp-idf/en/v4.0.4/api-reference/network/esp_now.html>`_.
In this way our boards will know the "ID" of the board they have to connect with.

To obtain the MAC address of our boards we can upload a very simple code, the following one is for the D1 mini with the ESP8266 microcontroller:

.. code-block:: arduino
    
    #include <Arduino.h>
    #include <ESP8266WiFi.h>

    void setup() {
    Serial.begin(115200);
    WiFi.disconnect();
    ESP.eraseConfig();

    // Wifi STA Mode
    WiFi.mode(WIFI_STA);

    // Get Mac Add
    Serial.println();
    Serial.print("Mac Address: ");
    Serial.print(WiFi.macAddress());
    }

    void loop() {
    // the loop does nothing
    }

This will print the mac address of the device on the serial monitor, which you can open by clicking on its icon on the top-right of the IDE, 
or by going to ``Tools -> Serial Monitor``, or with the shortcut ``Ctrl + Maiusc + M``.

|
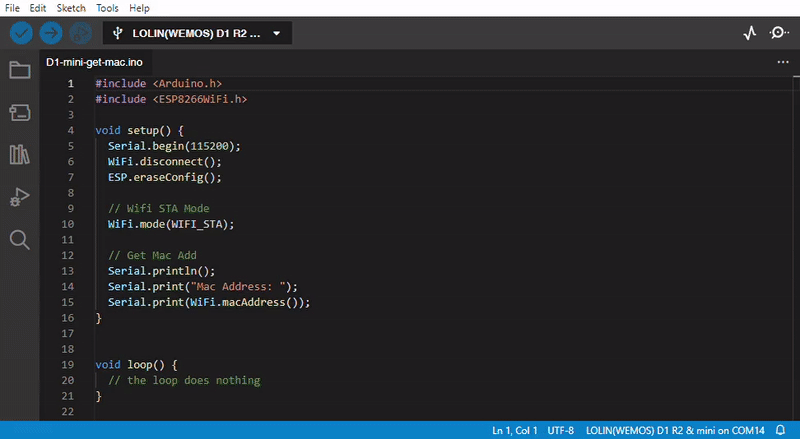
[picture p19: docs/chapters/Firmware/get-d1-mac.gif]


|
In this case the MAC address is 48:55:19:C6:6E:30

|

since the network controller of the microcontrollers are managed differently due to the different hardware resources we have to repeat the 
process with the dongle board but with a slightly different code, since the board we are using is based on the ESP32:

.. code-block:: arduino

    #include <Arduino.h>
    #include <WiFi.h>

    void setup() {
    Serial.begin(115200);

    // Set device as a Wi-Fi Station
    WiFi.mode(WIFI_STA);

    // Get Mac Add
    Serial.println();
    Serial.print("Mac Address: ");
    Serial.println(WiFi.macAddress());
    }

    void loop() {
    // the loop does nothing
    }

|
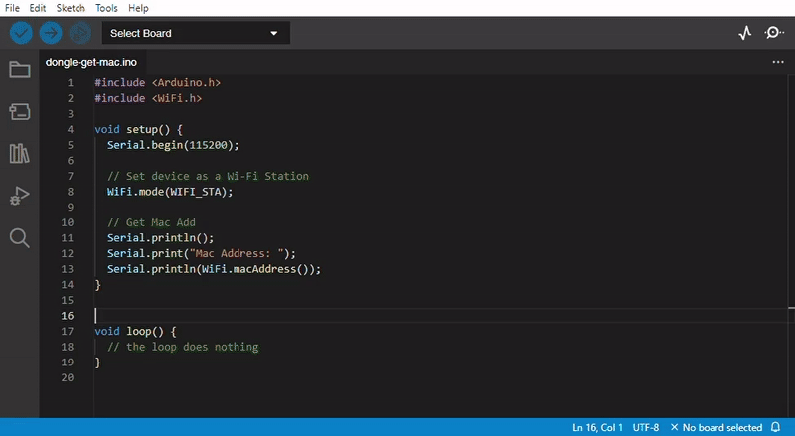
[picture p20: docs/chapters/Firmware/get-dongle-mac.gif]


|
In this case the MAC address is 78:E3:6D:0B:24:04

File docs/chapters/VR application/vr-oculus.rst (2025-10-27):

VR Application: Oculus Quest
==========================================================================

The Oculus Quest is a standalone VR headset developed by `Meta <https://meta.com/>`_ that does not require a computer to operate. It is ideal for VR applications, as it is wireless and features an advanced tracking system. Using inside-out tracking, the headset's cameras monitor the user's position in physical space. This enables a more immersive and interactive VR experience, allowing users to move freely without being tethered to a computer. Below is an image showing the application in action on the Oculus Quest 2 headset:

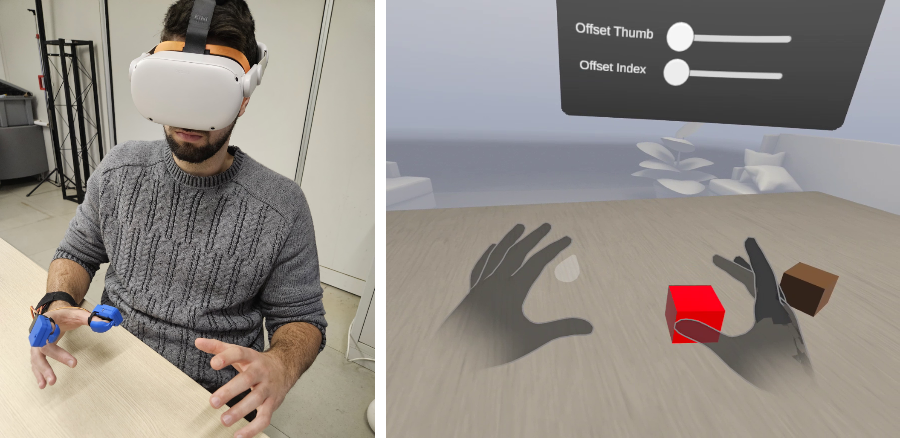
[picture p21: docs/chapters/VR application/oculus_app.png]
Oculus Quest application demonstration


|

Prerequisites
-------------

Before starting, ensure you have the following:

- A PC with Windows 10 or later (macOS is not supported for Oculus development with Unity).
- An Oculus Quest 2, Quest 3, or Pro headset.
- A compatible USB cable (e.g., Oculus Link cable or USB 3.0 cable for Quest devices).
- Unity Hub installed on your PC.

**Step 1**: Install Oculus Software
-------------------------------

Download and install the Oculus PC app (for Oculus Link). This software is required to connect your Oculus device to your PC for development.

- **Download link:** `https://www.meta.com/quest/setup/ <https://www.meta.com/quest/setup/>`_

After installation:

1. Open the app and follow the on-screen instructions to set up your Oculus device.
2. Enable **Developer Mode** in the Oculus smartphone app (details in Step 2).

**Step 2**: Enable Developer Mode
-----------------------------

1. Install the **Meta Quest Developer Hub** on your PC:
   - **Download link:** `https://developer.oculus.com/downloads/ <https://developer.oculus.com/downloads/>`_

2. Log in using your Meta (Oculus) developer account.
   - If you don’t have an account, create one here: `https://developer.oculus.com/sign-up/ <https://developer.oculus.com/sign-up/>`_

3. Connect your Oculus device to the Meta Quest Developer Hub and toggle **Developer Mode** on.

**Step 3**: Install Unity
---------------------

1. In Unity Hub, install a Unity Editor version compatible with the Oculus Integration SDK.
   - Recommended: Unity LTS version (e.g., Unity ``2021.3.26f1`` or higher, for compatibility with the ``Meta XR SDK``).

2. During installation, include the following modules:
   - **Android Build Support** (required for Oculus Quest development).

**Step 4**: Install Oculus Integration in Unity
-------------------------------------------

1. Open Unity and create a new 3D project.
2. Once the project is open, go to **File > Build Settings** and select **Android** as the platform.
3. Access the **Asset Store**:
   - In Unity, click **Window > Asset Store** (or open `https://assetstore.unity.com/ <https://assetstore.unity.com/>`_ in your browser).
4. Search for **Meta XR All-in-one** and download/import it into your project (tested with Meta version ``72.0``).
5. After importing, a window will appear for ``Meta XR Interaction``. Keep using the ``OVR Hand``.
6. Import the sample scenes from Meta XR Interaction via the Package Manager.

.. note::

   We use the Meta XR All-in-one package as it includes the Meta Core for visualization, Meta Interaction modules for physical interaction, and other useful demos.

|

**Step 5**: Configure Unity for VR Development
------------------------------------------

1. Go to **Edit > Project Settings > XR Plug-in Management** and enable **Oculus**.
2. Configure player settings:
   - Navigate to **Edit > Project Settings > Meta XR** and resolve all potential issues.

**Step 6**: Download the SimpleThimble Oculus Unity Package
------------------------------------------------

1. Download the SimpleThimble Oculus Unity package: :download:`here <SimpleThimble_oculusApp.unitypackage>`.
2. Import the package into Unity by dragging and dropping it into the **Assets** folder of your project.
3. In the Project window, navigate to the ``Scenes`` folder and open the Oculus demo.

.. note::
   This project uses UDP (User Datagram Protocol) for communication between the virtual scene and the thimbles. To enable this functionality, upload a specific firmware to the thimble (ESP8266). This provides a standalone solution, making the project more accessible.

|

**Step 7**: Connect the SimpleThimble via UDP and Run the Project
----------------------------------------

1. Download the firmware for the standalone version of the SimpleThimble: :download:`here <SimpleThimble_standaloneFirm.rar>`.
2. Connect the ESP8266 to your computer and upload the firmware using Arduino IDE.
3. Turn on the thimble and connect to the network ``simplethimble`` using the password ``password``.
4. Run the project in Unity. The following scene should appear:

Oculus demo scene

|

In the application, you can use your hands directly to interact with the virtual environment. The thimbles provide haptic feedback when touching virtual objects. Additionally, you can adjust the thimbles' offset using sliders with your left hand.

.. note::
   The right hand consists of two overlapping virtual hands. One serves for interaction (penetrating objects to compute haptic feedback), while the other provides visualization to simulate physical interaction.

|

**Step 8**: Bimanual Configuration (Optional) 
------------------------------------
A firmware plug-in containing the UDP communication code for a second SimpleThimble to use in bimanual mode is available :download:`here <SimpleThimble_biManipulation.rar>`. The code is made for a standalone version and connects via Wi-Fi to the same network as the first thimble. In the Unity implementation, you need to set the UDP port of the second thimble to receive values.

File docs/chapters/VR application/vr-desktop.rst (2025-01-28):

VR Application: Desktop 
+++++++++++++++++++++++++++++++++++++++++++++

This project aims at get acquainted with the SimpleThimble without using any tracking device. The idea is to move a virtual sphere on a surface populated with obstacles of varying shapes and heights. Users can move the sphere using the mouse or trackpad of their computer. In this scenario, we are using a simplified version of the SimpleThimble, which is composed of only of thimble to be worn on the index finger. This also proved the modularity of the SimpleThimble project, as we can easily adapt the hardware to different scenarios.

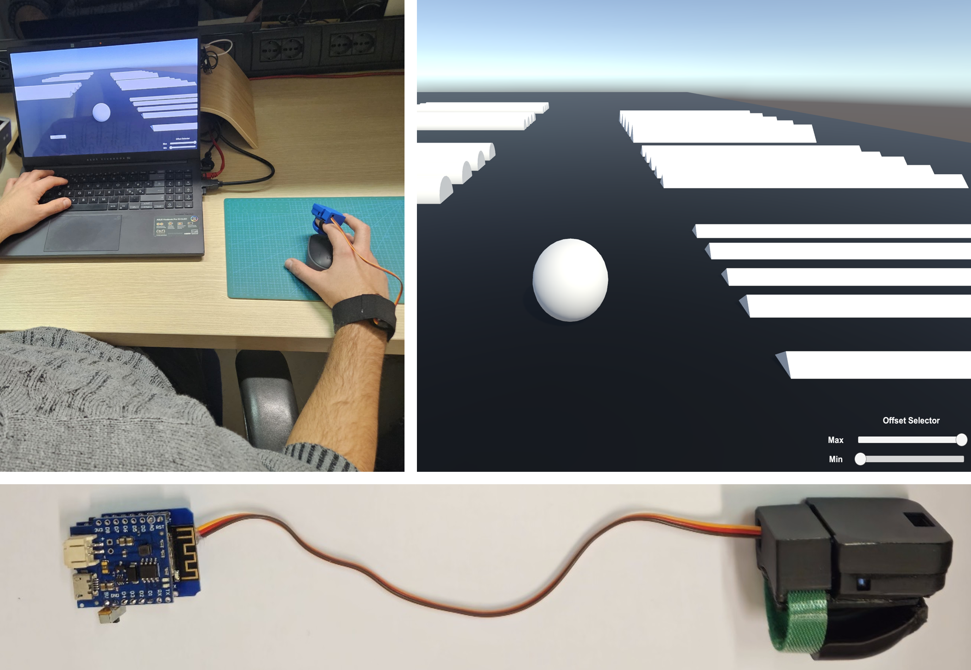
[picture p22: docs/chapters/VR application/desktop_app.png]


|

.. note::
   To adapt the SimpleThimble for the following demo, unplug the thimble used on the thumb and use only the thimble for the index.
|

Prerequisites
-------------

Before you begin, ensure that you have the following:
- A PC with Windows 10 or later (macOS is not supported for Oculus development with Unity).
- Unity Hub installed on your PC.

**Step 1**: Download and Open the SimpleThimble Unity Project
---------------------------------------------------------

**Download the SimpleThimble Unity package**: :download:`here <SimpleThimble_desktopApp.unitypackage>`.

**Open the Project in Unity**:  
   - Open **Unity Hub**.
   - Create a new Unity project with the 3D template.
   - Drag and drop the downloaded package to the Assests of your project.
   - It might be necessary to solve a problem for the SerialPort. If so, go to **Edit -> Project Settings -> Player -> Other Settings -> Configuration -> Api Compatibility Level** and select: .NET Framework

**Run the Project**:  
   - Adjust the resolution in Game window to ``Full HD (1920x1080)``.
   - Press the Play button to run the project.

**[Optional]** Make an executable file for running the development
--------------------------------------------------------------

**Build Settings**:  
   - Go to **File -> Build Settings**.
   - Add the current scene to the build.
   - Select the target platform (Windows, Mac, Linux).
   - Press Build and Run.

**Step 2**: Play the Game
---------------------
When running the project, you should see an environment similar to the following image:

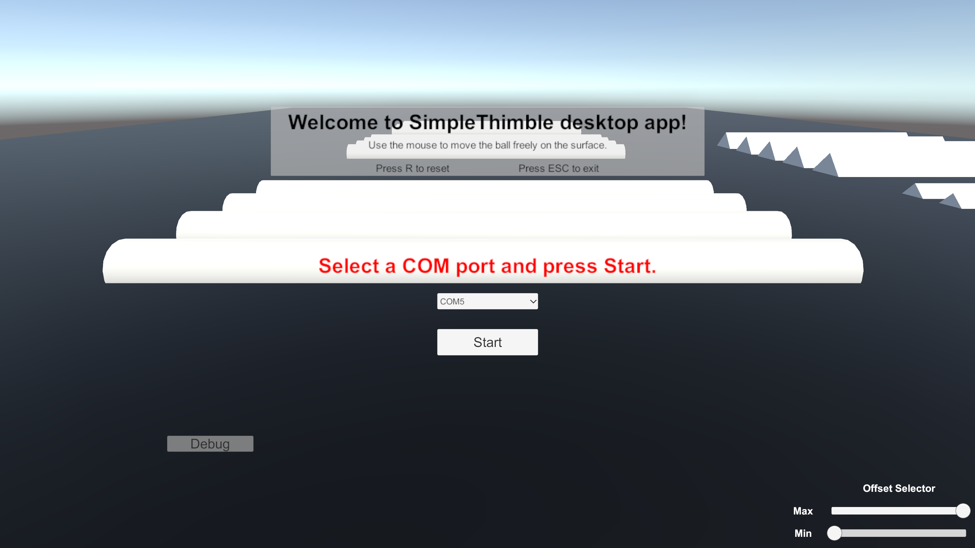
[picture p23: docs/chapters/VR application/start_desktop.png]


|

In the application, you need to select the ``COM`` port where the dongle is connected to your computer. Additionally, at the bottom right corner, you will see two sliders for offset adjustments. These offsets are used to set the minimum and maximum values of the force feedback. On the right side, there is a ``Debug`` panel for debugging without opening the serial connection. Once you press the ``Start`` button, you can move the sphere using your mouse or trackpad. The sphere will navigate the surface and collide with obstacles, while the thimble generates force feedback upon collision. The demo will look like the following:

pref

|

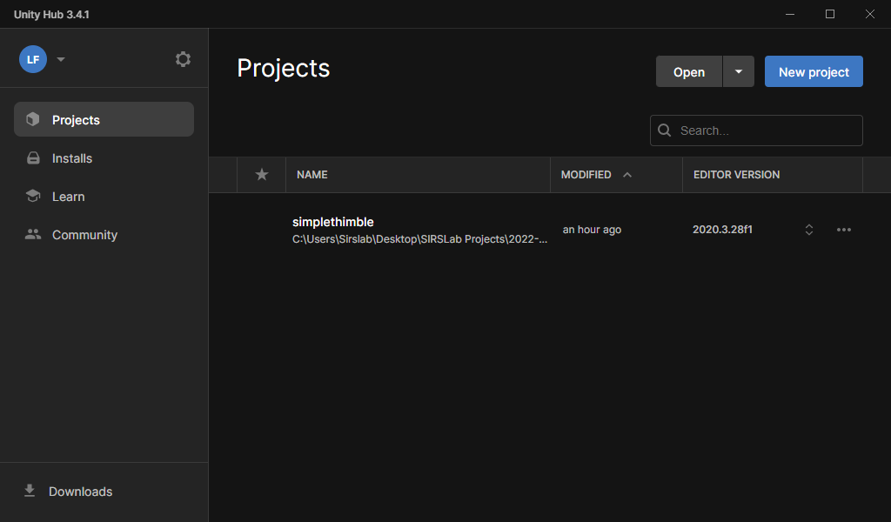
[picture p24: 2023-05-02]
docs/chapters/VR application/unityhub.png

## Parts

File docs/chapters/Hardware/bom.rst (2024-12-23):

Bill of Materials
+++++++++++++++++++++++

.. tip:: 
    Doing a project with friends can be a great way to lower the cost for each participant. By pooling resources and splitting the cost of materials, you can save money and still get the job done. Plus, you'll have the added benefit of having friends to help you out and provide moral support. Working together can also help you stay motivated and on track, so you can finish the project faster and with better results. So why not get your friends together and start your project today?

.. list-table:: Bill of Materials
    :widths: 20 10 10
    :header-rows: 1

    * - Item
      - Link
      - Cost
    * - D1 mini proto-shield 
      - https://amzn.eu/d/5keiUkw
      - 6,49 €
    * - D1 mini ESP8266 board
      - https://amzn.eu/d/aI0mK40
      - 8,99 €
    * - ESP32 board
      - https://amzn.eu/d/aYQShuS
      - 8,60 €
    * - D1 mini battery-shield
      - https://amzn.eu/d/akHmwFU
      - 8,99 €
    * - Velcro stripes
      - https://amzn.eu/d/3heTWBR
      - 11,30 €
    * - Switches
      - https://amzn.eu/d/442j59V
      - 8,88 €
    * - LiPo Battery
      - https://amzn.eu/d/aGKZpqY
      - 29,99 €
    * - SG90 Micro Servo Motor
      - https://amzn.eu/d/9NTOj6Y
      - 16,99 €
    * - Soft tape
      - https://amzn.eu/d/55o6gIk
      - 13,89 €

Even though the total is **104,5 €** in materials, we advice the reader that some costly items (such as the LiPo battery or the microcontroller) are sold in more than one unit. The cost for a single pair of thimbles could be reduced to under **30 €**.

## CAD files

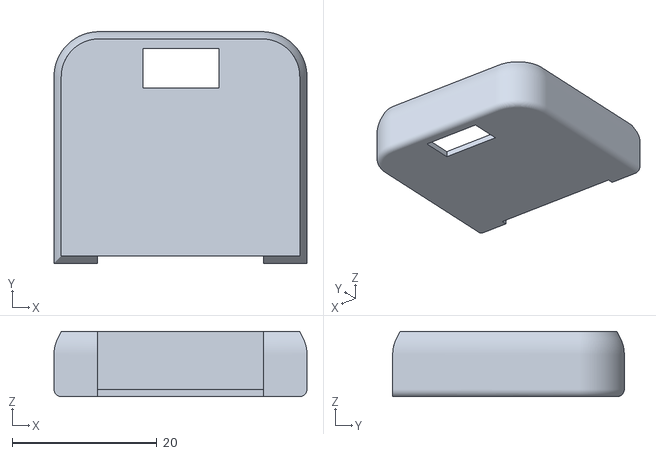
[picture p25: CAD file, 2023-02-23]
docs/chapters/3D-Printing/covers/cover.stl
34.9 x 32.0 x 9.00

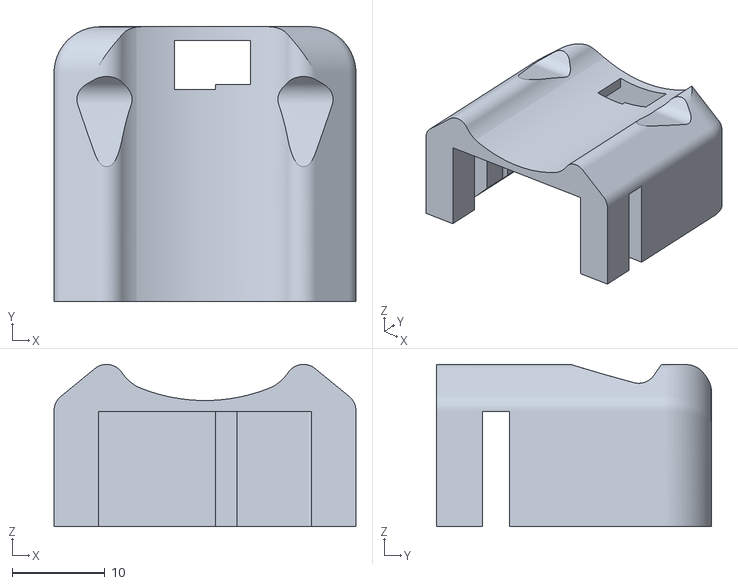
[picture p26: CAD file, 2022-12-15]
docs/chapters/3D-Printing/main-box/finger-servo-adapter.stl
32.5 x 29.6 x 17.4

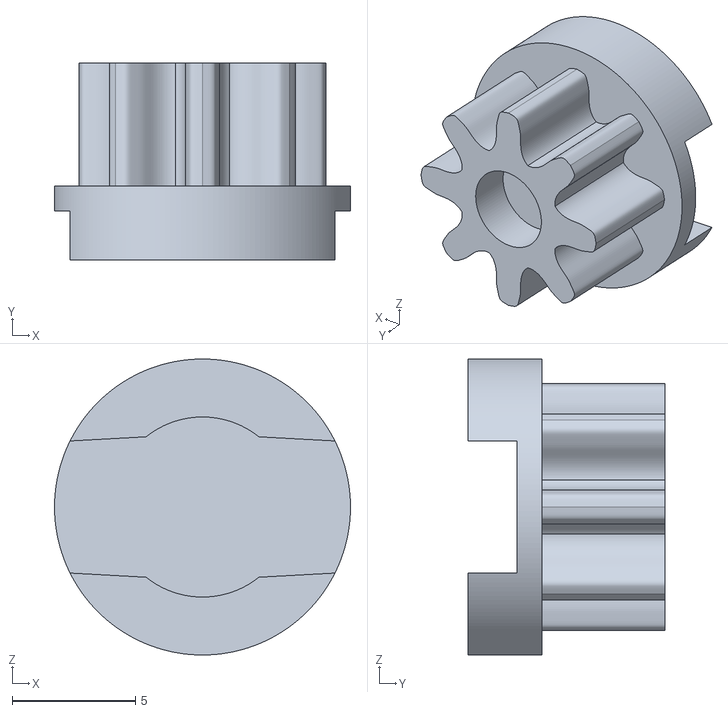
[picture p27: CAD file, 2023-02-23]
docs/chapters/3D-Printing/rack-pinion/pinion.stl
12.0 x 8.00 x 12.0

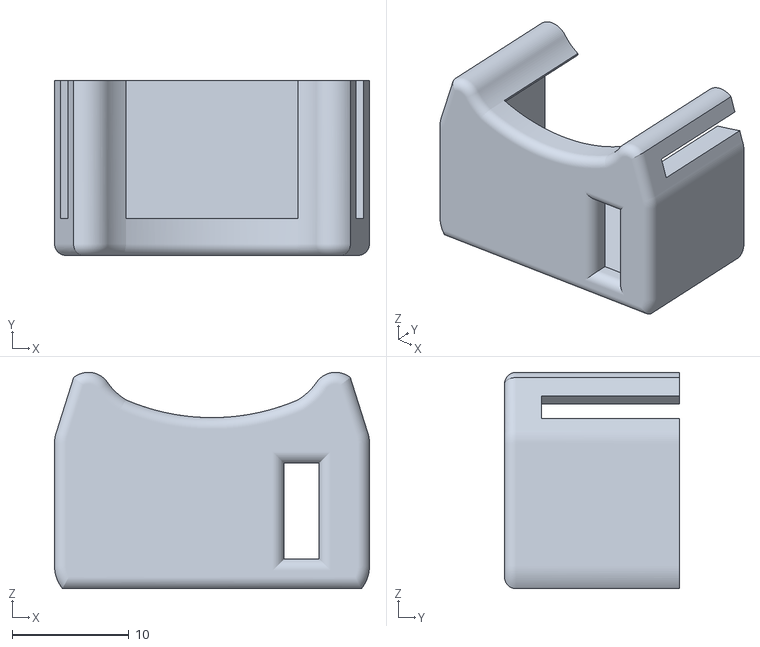
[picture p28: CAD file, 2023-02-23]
docs/chapters/3D-Printing/covers/back_cover.stl
27.0 x 15.0 x 18.5

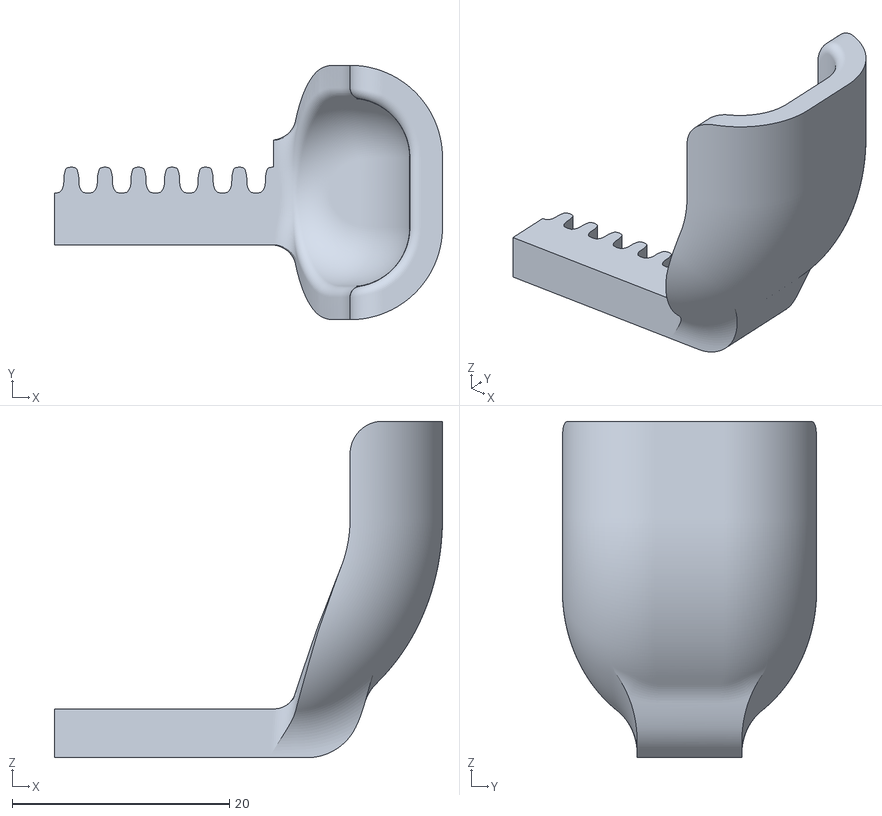
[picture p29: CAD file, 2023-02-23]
docs/chapters/3D-Printing/rack-pinion/rack.stl
35.7 x 23.4 x 31.0

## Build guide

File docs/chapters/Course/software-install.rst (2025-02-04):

SimpleThimble Course: Arduino IDE Setup for ESP32 and ESP8266
========================================

This guide provides step-by-step instructions on how to configure the Arduino IDE to work with ESP32 and ESP8266 boards.

Prerequisites
-------------

- **Arduino IDE Version**: 2.3.1  
  Download for Windows (64-bit): `Arduino IDE 2.3.1 <https://github.com/arduino/arduino-ide/releases/download/2.3.1/arduino-ide_2.3.1_Windows_64bit.msi>`_

---

Setup Instructions
------------------

Step 1: Install Arduino IDE
^^^^^^^^^^^^^^^^^^^^^^^^^^^

1. Download the `Arduino IDE 2.3.1 <https://github.com/arduino/arduino-ide/releases/download/2.3.1/arduino-ide_2.3.1_Windows_64bit.msi>`_.
2. Run the ``.msi`` file and follow the installation instructions.

---

Step 2: Add ESP Board Manager URLs
^^^^^^^^^^^^^^^^^^^^^^^^^^^^^^^^^^

1. Open Arduino IDE.
2. Navigate to **File -> Preferences**.
3. Scroll to the "Additional Boards Manager URLs" field and click the blue icon to open the input field.
4. Add the following URLs:

.. code-block:: bash

    https://dl.espressif.com/dl/package_esp32_index.json
    https://raw.githubusercontent.com/espressif/arduino-esp32/gh-pages/package_esp32_index.json
    https://arduino.esp8266.com/stable/package_esp8266com_index.json

5. Click **OK** to save and close the Preferences window.

---

Step 3: Install ESP32 and ESP8266 Board Packages
^^^^^^^^^^^^^^^^^^^^^^^^^^^^^^^^^^^^^^^^^^^^^^^^

1. Go to **Tools -> Board -> Board Manager**.
2. Search for ``esp`` in the search bar.
3. Install the following packages:

   - **ESP32 by Espressif Systems (version 2.0.5)**
   - **ESP8266 by ESP8266 Community (version 2.7.4)**

---

Troubleshooting
---------------

Missing Drivers
^^^^^^^^^^^^^^^

1. Open **Device Manager** on your system and check the type of USB-to-UART conversion chip being used.
2. Based on the chip type, download the corresponding driver. For example:

   - If the chip type is **USB-SERIAL CH340**, download the driver from `this link <https://sparks.gogo.co.nz/ch340.html>`_.

3. Additional drivers:

   - **ESP8266 Drivers**: `Download CP210x Drivers <https://www.silabs.com/documents/public/software/CP210x_Windows_Drivers.zip>`_  
   - **ESP32 Drivers**: `Install CH9102 Drivers <https://learn.adafruit.com/how-to-install-drivers-for-wch-usb-to-serial-chips-ch9102f-ch9102/windows-driver-installation>`_

---

Additional Resources
--------------------

- `Official Arduino IDE Documentation <https://www.arduino.cc/en/software>`_
- `ESP32 GitHub Repository <https://github.com/espressif/arduino-esp32>`_
- `ESP8266 GitHub Repository <https://github.com/esp8266/Arduino>`_

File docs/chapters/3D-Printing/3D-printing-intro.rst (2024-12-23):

3D-Printing Introduction
++++++++++++++++++++++++
.. _3dPrintingIntro:

In this section we will guide you to 3D print all necessary components for the build. Here you can see some features of the Simple Thimble:

rotating-thimble

Tools Required
==============
* 3D Printer
* 3D printing filament
* cutter
* files
* sanding paper

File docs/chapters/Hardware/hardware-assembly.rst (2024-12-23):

Welcome to the hardware assembly section!
+++++++++++++++++++++++++++++++++++++++++

In this section we will guide you to put together all the components to make the Simple Thimble!

.. caution::
    The project mechanics has been designed to be self produced with low-cost FDM (fused deposition modeling) 3D printing

.. danger:: 
    To obtain properly working 3D printed mechanical parts, you may need to file some parts to make them fit together. Moreover, soldering parts is needed to make this project.
    Always wear the proper **safety equipment**. This includes ``safety glasses`` to protect your eyes from flying debris, a ``face mask`` to protect your lungs from fumes, and ``gloves`` to protect your hands from heat and sharp edges. Additionally, it is important to work in a *well-ventilated* area to reduce the risk of inhaling toxic fumes.

Tools Required 
=============== 
* Soldering Iron 
* Solder 
* Wire Strippers 

Assembly Instructions 
========================== 

.. note:: 
    Some assembly instructions can be swapped without affecting the final result. This is because the order of instructions does not always matter. For example, if two instructions are independent of each other, they can be swapped without changing the outcome.

|
|
Step 1: Create the servomotor-pinion assembly - cut and place the servo adapter to the pinion
-------------------------------------------------

The first step to build our thimble is to attach the pinion to the servomotor shaft. 
First, cut the excess extremities of the servo plastic adapter and press-fit it into 
the pinion.

step1

|
|
Step 2: Create the servomotor-pinion assembly - mount the pinion-adapter assembly to the motor
-------------------------------------------------

This passage is straightforward, you just need to use the pinion as a modified servo adapter.

step2

|
|
Step 3: Insert the rack and assamble with the servomotor-pinion assembly
-------------------------------------------------

Once you have the servo-pinion assembly, you can mount the rack in the main box. Then, keeping 
the rack to its final position (thimble to maximum compression), instert the servo-pinion assembly 
making sure to engage the pinion as low as possible on the rack.

step3

|
|
Step 4: Mount the main cover on
-------------------------------------------------

Now you can mount the main cover on top of the main box by press fitting it in place.

step4

|
|
Step 5: Secure the servomotor connection
-------------------------------------------------

Cheap servomotors such as the SG-90, do not offer quality cabling, so to increase the life of such 
servomotors it is strongly recommended to glue the cable coming out from the servo chassis to the 
chassis itself

step5

|
|
Step 6: insert the back cover
-------------------------------------------------

Now you can insert the connector of the servomotor in the hole of the back cover. You can insert 
the back cover on the servo but not completely, we need some space for the next step.

step6

|
|
Step 7: Insert the velcro strip and the neoprene tape
-------------------------------------------------

In the gap we left in the previous step we can now insert the suitably cut velcro strip necessary to secure 
the thimble to the finger. After that we can add the neoprene tape to the lower part of the thimble.

step7

|
|
Step 8: Wear the SimpleThimble!
-------------------------------------------------

Now you can wear the SimpleThimble and test if the servomotor works, or with a `servo tester <https://amzn.eu/d/bgud9uM>`_, or by :ref:`programming 
our microcontroller<onboardFirmware>`.

step8

|
|
Step 9: Solder connectors to the microcontroller
-------------------------------------------------

Our final step is to solder two male dupont connectors to our `D1 mini ESP8266 board <https://amzn.eu/d/aI0mK40>`_. 
Specifically the Ground cable (usually black or brown) and the Power pin (usually red) respectively to the pin 
G (GND or Ground) and the pin 5V of the D1 mini ESP8266 board. The control cable of the two servomotors must be 
soldered to IO pins D5 (`GPIO <https://en.wikipedia.org/wiki/General-purpose_input/output>`_ 14) and D6 (GPIO 12) 
of the D1 mini ESP8266 board.

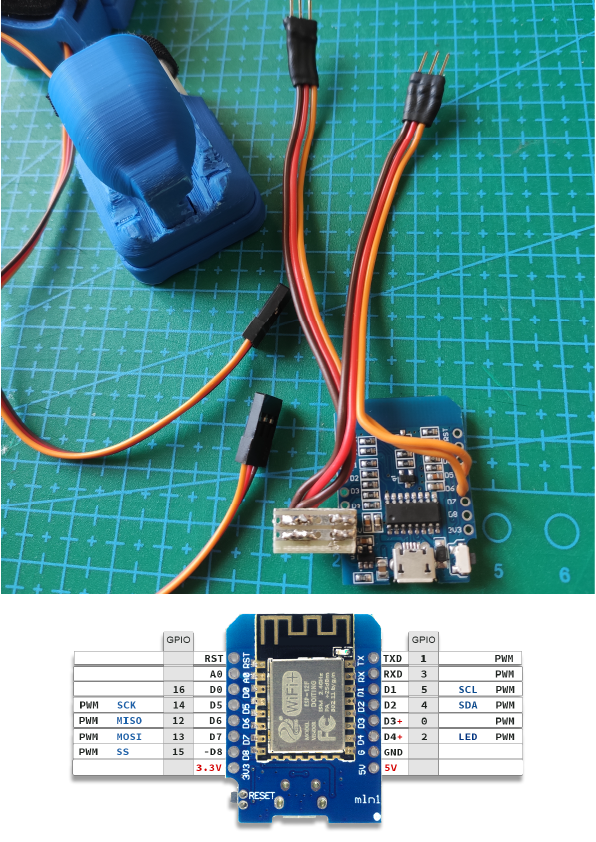
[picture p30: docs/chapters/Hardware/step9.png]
step9


|

Another important thing to solder is a connector for the battery.
The fastest way to go is to cut a piece of `stripboard <https://en.wikipedia.org/wiki/Stripboard>`_ and solder both 
the battery connector and the power cables of the servomotors to the power pins of the D1 mini board.

battery connector soldered

|

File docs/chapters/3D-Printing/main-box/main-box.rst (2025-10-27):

Main Box
++++++++

The main box is the central 3D printed part which houses directly the motor 
and accomodate the shape of our finger.
You can download the .stl file :download:`here <finger-servo-adapter.stl>`.

Main Box Image

finger-servo-adapter
|

The function of this 3D printed part is to provide a mechanical linkage 
between the servomotor and the finger and ensure that the actuation part is 
precisely aligned with the fingertip pulp. The 3D printed part serves as a 
connector that translates the rotational motion of the servomotor into a 
precise alignment with the fingertip, resulting in accurate and consistent 
squeezing of the fingertip pulp.

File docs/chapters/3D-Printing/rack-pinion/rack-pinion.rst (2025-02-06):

Rack and Pinion
++++++++

These two 3D printed parts are the rack and pinion, which will be mounted 
inside the thimble to convert the rotary motion of a servomotor into linear 
motion. The rack is a toothed bar that meshes with the pinion, a gear with a 
small number of teeth. When the pinion rotates, it drives the rack in a linear 
motion, resulting in precise and controlled movement of the thimble.

The rack and pinion mechanism is commonly used in mechanical systems to 
convert rotary motion to linear motion. In this particular case, it is used 
to translate the rotational motion of the servomotor to a linear motion that 
can be used to manipulate objects or instruments with the thimble. The 3D 
printed parts are designed to fit precisely inside the thimble and mesh 
smoothly with each other, ensuring reliable and accurate conversion of motion.

rack-pinion
|

You can download the .stl file of the rack :download:`here <rack.stl>` and 
that of the pinion :download:`here <pinion.stl>`.

In addition to converting rotary motion to linear motion, the rack and pinion 
mechanism also includes an ergonomic fingertip envelope at the end of the rack. 
This envelope is designed to apply equal pressure on all surfaces of the 
fingertip, ensuring precise and controlled manipulation of objects or instruments. 
The design of the 3D printed parts takes into account both functionality and 
comfort, allowing for efficient and ergonomic use.

Rack and Pinion image
|

The design of these 3D printed parts was also done with ease of printing in mind, 
using fused deposition modeling (FDM) technology. This method allows for quick 
and precise production of parts using a variety of materials. The design takes 
into account the limitations of FDM printing, ensuring that the parts can be 
printed easily and without errors. This ensures that the parts are readily 
available and easy to produce, making them a cost-effective and accessible 
solution for converting rotary motion to linear motion.

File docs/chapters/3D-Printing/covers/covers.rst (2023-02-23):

Covers
++++++++

covers

The two 3D printed parts are the main box cover and the rear cover, 
which serve important functions in the overall design.

You can download the .stl file of the main cover :download:`here <cover.stl>` and 
that of the rear cover :download:`here <back_cover.stl>`.

The main box cover is not only aesthetically pleasing but also functional. As it 
interlocks with the main box, it helps to hold the servomotor in place, 
ensuring that it remains stable during use. This is essential for accurate 
and reliable manipulation of objects or instruments with the thimble.

Covers image

The rear cover, on the other hand, was designed with two main purposes in mind. 
Firstly, it covers the servomotor cable and holds it in place with glue, as 
the quality of cable soldering is notoriously poor. This ensures that the 
cable remains securely in place, preventing any unwanted movement or 
disconnection during use. Secondly, the rear cover hosts the Velcro strip 
that is used to secure the thimble to the finger. This allows for easy and 
comfortable use of the thimble, ensuring that it remains securely attached 
to the finger throughout use.

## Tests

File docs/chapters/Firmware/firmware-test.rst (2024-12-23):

Firmware test code
++++++++++++++++++

To familiarize with the arduino IDE and write our first **firmware code**, we will write and upload a test code into our D1 mini microcontroller.
This code is an example of testing if your device is working as expected.

Setup the environment to program the D1 mini ESP8266 board
============================================================

To upload a code to our microcontroller it is necessary to tell the IDE on which COM port of the computer we connected our device 
and also which board is. This is important because depending on the board the compiler will link different libraries of code and 
also differen hardware definitions of pins. In our case we have to first connect our D1 mini ESP8266 board by using a USB micro 
connector.

connect board

|

Now we can click on the black drop-down menù which says "Select Board" and now we can click on "Select other board and port...". 
Another window will pop-up: in the left part there is a search bar and we can search for our specific board here. As soon as 
we write "D1" we are left with the first option being "LOLIN(WEMOS) D1 R2 & mini", select it. In the right part of this pop-up 
menù we can select the COM port on which we have connected the board, to identify which to select, next to one of the options 
there is written "(USB)", select that. Now we can click "OK" and the pop-up menù will be closed, and in the bottom-right corner 
of the IDE will now appear which board we intend to program and on what USB COM port it is.

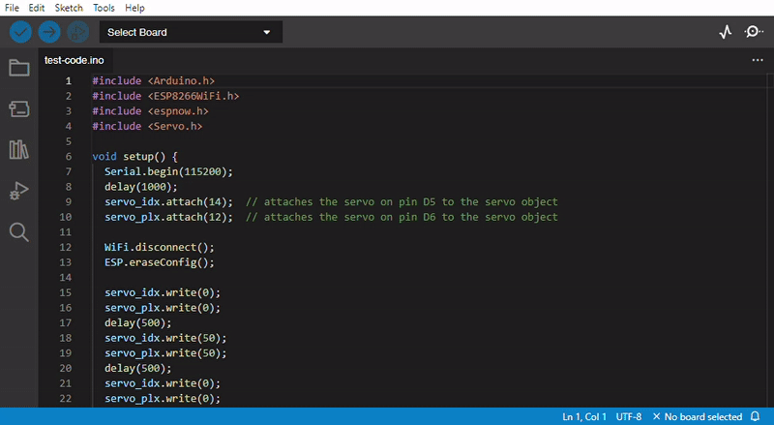
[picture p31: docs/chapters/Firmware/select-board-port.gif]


|

The test code
==============

The following code will help you verify that your device is functioning correctly and that all its components are working properly. 
This code will just move the servomotors as soon as the board is powered:

.. code-block:: arduino

    #include <Arduino.h>
    #include <ESP8266WiFi.h>
    #include <espnow.h>
    #include <Servo.h>

    Servo servo_idx;   // create servo object to control a servo
    Servo servo_thmb;  // create servo object to control a servo

    void setup() {
        Serial.begin(115200);
        delay(1000);
        servo_idx.attach(14);  // attaches the servo on pin D5 to the servo object
        servo_thmb.attach(12);  // attaches the servo on pin D6 to the servo object

        WiFi.disconnect();
        ESP.eraseConfig();

        servo_idx.write(0);
        servo_thmb.write(0);
        delay(500);
        servo_idx.write(50);
        servo_thmb.write(50);
        delay(500);
        servo_idx.write(0);
        servo_thmb.write(0);

        // Wifi STA Mode
        WiFi.mode(WIFI_STA);

        // Get Mac Add
        Serial.println();
        Serial.print("Mac Address: ");
        Serial.print(WiFi.macAddress());
    }

    void loop() {
        // loop does nothing.
    }

Verify and Upload!
==============

Now that you copied the code in the text editor of the IDE you can proceed to Verify your sketch.

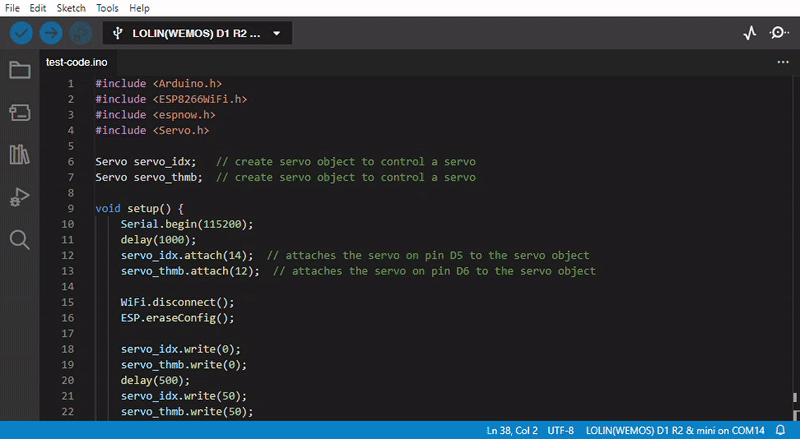
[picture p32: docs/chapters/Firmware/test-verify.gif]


|

And after that you can click the upload button. You will notice the blue LED of the board flashing as the code is flashed 
into the microcontroller memory and at the end of the procedure the code will be executed: as a result, our thimbles will 
move for the first time!

pref

|

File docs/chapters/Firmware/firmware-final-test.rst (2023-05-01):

One final test for the Simple Thimble firmware
+++++++++++++++++++++++++++++++++++++++++++++
In this section we will make sure that all firmwares we uploaded to the microcontrollers 
work together.

To do this we have to connect just the dongle to one of our USB ports and battery-power the 
thimble microcontroller with the servomotors attached.

Once everything is wired, we can use the ``Tools -> Serial Monitor`` to write data directly to the dongle via USB.
This will result in the dongle sending this serial data wirlessly to the other board controlling the thimbles via 
ESP-NOW protocol.

In the next animated image you can see this final test performed: the user types the characters "AA" and "zz" to the 
serial port with the result of the thimbles moving to reach this positional command

|
pref

|

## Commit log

2022-12-15 added first downloadable .stl file
    [finger-servo-adapter.stl]
2023-02-23 nested main box in a self named folder
    [finger-servo-adapter.stl]
2023-02-23 added rack and pinion
    [pinion.stl, rack.stl]
2023-02-23 added cover part
    [back_cover.stl, cover.stl]
2023-02-24 item added to bom
2023-02-24 added esp board image
2023-03-01 added gifs to hardware assembly
2023-03-01 mod hardware assembly and onboard firmware
2023-03-02 added image of battery connector
2023-03-02 added board manager gif
2024-12-23 ristrutturato tutto
    [back_cover.stl, cover.stl, finger-servo-adapter.stl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]
